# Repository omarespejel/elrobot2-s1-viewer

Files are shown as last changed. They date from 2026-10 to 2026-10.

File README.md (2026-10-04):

# ElRobot2: design versions

Open the site from this repository's GitHub Pages link. The landing page shows the versions of a robot-arm
design that restocks cans and PET bottles through the rear of a convenience-store cooler, with the numbers
that separate them.

## Contents

* `index.html`: versions (S1 v1.1, S2-RC2 release candidate), version history, caveats.
* `viewer/index.html`: interactive 3D viewer of S1 v1.1 (a single self-contained page with six simulation replays).
* `viewer-s2/index.html`: interactive 3D viewer of the S2-RC2 neck-grip hand on the S1 arm (a single self-contained page with seven simulation replays).
* `report.html`: the S1 design report (third round, 2 October 2026).
* `report-s2.html`: the S2-RC2 design report (4 October 2026).
* `docs/`: parameters, test plan, risk register, review log, evidence table, measurement sheet, track reports (Hand, Wrist, Simulation), desk-research pack and module notes.
* `img/`: figures used in the reports.

## What this is and is not

* S1 (top-down gripper) and S2-RC2 (collar jaws that hold a bottle by the neck) are drawn in CAD, checked with exact-mesh
  interference tests and finite-element or closed-form strength checks, and simulated in MuJoCo on a stand-in bench.
  The viewers replay those simulations on the CAD.
* The cooler outline in the viewers is illustrative. Rack dimensions in the reports are inferred from public
  catalogues (US manufacturers, Mexican resellers); no real cooler was measured. The S2-RC2 bottle neck is assumed (PCO-1881) until it is measured.
* **Nothing in this design has been printed, built or measured.** Every dimension, mass and margin is CAD,
  hand calculation, simulation or desk research.
* Scope: aluminium cans (S1) and one-way PET bottles (S2-RC2: 500 and 600 mL verified, 1 L conditional). Glass and returnable containers are out of scope.

The pages carry a noindex tag so that search engines are asked to skip them.

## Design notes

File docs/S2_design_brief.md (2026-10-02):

# S2 end-of-arm design brief: offset wrist, neck-jaw (PET) and flat clamp (cans)

Status: concept brief written on 2026-10-02 from the desk research (ElRobot2_desk_research_pack.md). No S2 part exists in CAD, no S2 motion has been simulated, and nothing has been tested. Values marked ASSUMED or VERIFY must be checked on the first bottle or print.

## 1. Problem

The v1 stack (gripper, J3 servo and L2 cover) stands 140 mm above the object top. A standard rack leaves 15-109 mm above a 600 mL bottle (pitch 0.287-0.381 m, structure 30 mm, margin 5 mm). v1 therefore cannot serve a 600 mL or larger PET bottle in any of the five standard configurations (Figure 9); a 500 mL bottle fits only in the sparsest rack and only if the structure is thinner than about 26 mm. Only a part that is thin where it enters the shelf tunnel (y above 245 mm) can.

## 2. Requirements

| ID | Requirement | Value | Basis |
|---|---|---|---|
| R1 | Structure above the cap inside the tunnel (neck-jaw) | at most 15 mm | gap 15 mm at 0.287 m |
| R2 | Structure above the can top inside the tunnel (flat clamp) | at most 50 mm | gap 94 mm for a tall can at 0.287 m; 50 mm leaves margin |
| R3 | J3 servo, end of L2 and every part taller than R1/R2 | stay at y at most 233 mm at the place pose | tunnel mouth at y = 253 mm, 20 mm margin |
| R4 | Tool offset L3 (J3 axis to neck axis) | 100 mm (85-130 mm) | stack front edge 230 mm; J3 radius 205-273 mm inside 170-385 mm |
| R5 | Static moment at J3 | 0.83 N*m (0.65 kg), 1.25 N*m (1.07 kg) | tool 0.20 kg at 100 mm |
| R6 | J3 bearing pair | two 6701-2RS, 30 mm apart: 28-42 N per bearing | 6701 is in the inventory (x20) |
| R7 | L3 bar stiffness | section at least 6000 mm4 in PETG (20 x 16 mm: 0.6 mm droop) or aluminium | 20 x 10 mm droops 2.5 mm |
| R8 | Tool mass | at most 0.25 kg | v1 gripper 0.336 kg |
| R9 | Hold | form closure on the support ring for PET; friction not required | friction is unmeasured (0.2-1.0 in the literature) |
| R10 | Accelerations while a bottle hangs | at most 0.3 g | swing about the neck |
| R11 | Lane | 75 mm (600 mL class), 90 mm (1 L); bottle clearance 3.6-5 mm per side | glide data |
| R12 | Tote | single row, pitch at least 85 mm, open on the arm side, necks reachable horizontally | neck-jaw approach is horizontal |
| R13 | Rack mock-up | pitch adjustable 0.29-0.44 m in 10 mm steps, 75 mm lane inserts, 6-8 deg slope | envelope range |

## 3. Offset wrist

J3 keeps its servo (STS3215 C018) and flange (50 mm, bolts on a 36 mm square). An adapter carries a bearing housing (two 6701-2RS) and the L3 bar, so that the servo transmits torque only and the bearings carry the moment. The tool centre point is the neck axis: J3 = TCP - L3 * u(heading). For lane targets at y = 305 mm the J3 axis sits at y = 205 mm; the stack front edge is then 230 mm. VERIFY: the existing J3 pin and its bearing (14 mm pin, 46 mm flange in the v1 CAD) were designed for a hanging gripper with its centre of mass on the axis; if they cannot take 1.25 N*m, replace the pin by the bearing housing (one small part).

## 4. Neck-jaw (PET)

- Two jaw plates, 3 mm thick, closing along x just below the support ring (ring underside about 18 mm below the cap top, ASSUMED from the 17.0 mm finish height; VERIFY in H1), a fixed back stop behind the neck, a U-notch of about 30 mm (ASSUMED: ring outside diameter 33 mm, so 1.5 mm ledge per side; the neck under the ring is about 25 mm in the standards and 24.5 mm is the smallest under-neck diameter in an air-conveyor catalogue; VERIFY on 5-10 bottles). Air conveyors use the same principle for empty bottles. Jaw stroke about 6 mm per side (open 40 mm, closed 28 mm), so a small-stroke linkage on one STS3215 is enough.
- The weight rests on the ring ledges (about 30 mm2 of contact: 0.2 MPa for 0.65 kg, 0.35 MPa for 1.07 kg); the closing force (at least 10 N on the neck) only prevents swing.
- Jaw mechanism block (servo and linkage) behind the neck, top at most 8 mm above the cap, partly inside the tunnel mouth (front at y = 275 mm).
- Acquire: approach horizontally at ring height minus 3 mm until the neck touches the back stop, close, lift 5 mm so the ring seats, then carry. Release: lower to the glide, open, retreat along -y.
- Open questions: free neck below the ring (3 mm jaw needs at least 4 mm), tamper bands and sports caps, sleeve labels, swing damping.

## 5. Flat clamp (cans)

Rack-and-pinion clamp with the pinion axis along x and one rack above and one below it (stack: pinion 24 mm + two racks 6 mm + clearances, about 48 mm), servo lying behind the clamp in the corridor, fingers closing along the lane axis as in v1. Clamp force and pad parameters as v1 (34.7 N per finger rated, 41.7 N cap); cans need 14 N at friction 0.4 and 19 N at 0.3. Printed TPU 95A pads are acceptable for cans; use cast polyurethane or silicone pads for a 1 L.

## 6. What S2 reuses

Z module, base, J1/J2 turret, L1, L2, electronics, camera and the calibration scripts. New parts: adapter and bearing housing, L3 bar, neck-jaw, flat clamp, tote tray (single row), rack mock-up with adjustable pitch and 75 mm lane inserts. The v1 gripper stays as a development tool for level-1 (open-top) tests.

## 7. Validation sequence

1. CAD of the new parts with fit checks against the STS3215, a PCO-1881 neck model (ring 33 mm ASSUMED) and a rack model at pitches 0.287, 0.318 and 0.381 m; reach study over five lanes (75 and 90 mm) and the tote.
2. MuJoCo: a bottle hanging from the jaws (ring contact), swing under planned accelerations, release into a 75 mm lane, placement error budget (clearance 3.6-5 mm against servo backlash of 3.4 mm at full reach).
3. Bench (Phase H1-H6 of the test plan): printed neck stub, then real bottles, then rack mock-up.
4. Gate: if H3 (placement into a 75 mm lane at 0.318 m) is below 9 of 10 after two design iterations, build the push-in plate.

## 8. Risks (also in the risk register)

Neck geometry variability; swing; placement tolerance in 75 mm lanes; J3 moment; the 5 mm margin and 30 mm structure thickness are assumptions; a Z range of 0.37-1.06 m reaches only 2-3 shelves of a 1.9-2.2 m rack.

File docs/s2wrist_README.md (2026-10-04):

# S2-RC2 WRIST track - J3 verification, CAN-mode bar, J3 kits, mode switch, reach (file prefix s2wrist_)

Generated by `s2wrist_make_readme.py` from the CSV/JSON files named in brackets, 2026-10-03.  Environment `robodesign` (cadquery 2.8.0, trimesh 5.1.0, manifold3d, numpy/pandas).  Frames: arm zeta frame, J3 interface plane z = 62.5 (flange bottom), heading +x in the J3 frame.  All lengths mm, forces N, moments N*m unless a unit is given.  ASSUMED = a value I chose, not measured or published.

## 0. Deviations and open items (read first)

1. **CAN-mode lane placement is NOT validated with this hand: the retreat after release collides (gate G1 not met for CAN lane placement).** Source: the lead's exact-mesh audit of the `s2wrist_can_mode_*_j3frame.stl` meshes (script `s2chk_can.py`, results `s2chk_can_C_v2.csv`, saved by the lead; this track did not run or reproduce it): 36 configurations (lanes 1 / 3 / 5 x levels 0 / 1 x pitch 0.287 / 0.318 m x 3 cans), 16 poses each, neighbouring cans in the other lanes, positive controls pass. Insert 252 / 252, lower 36 / 36 and release 36 / 36 are clean (the 355 mL can can only be lowered to 0.5 mm above the floor margin because the finger tips end 2.0 mm below its bottom). On the straight retreat the first step (the release pose) is clean, but all 216 / 216 later poses collide: `hand_slider_plus` (the front finger, closing axis = heading) against the released can (1.8-48.3 cm3 per pose, median 42.2 cm3). A lift-over needs >= 130 mm of lift to clear the can top, but the hand reaches the tunnel ceiling after 20 mm (p = 0.287 m) / 50 mm (p = 0.318 m) of lift with the 473 mL can and after 50 mm / 80 mm with the 355 mL can, so no lift-over exists; only p = 0.381 m with the 355 mL can has a window (130-140 mm). Consequence: this track's R_can / p_min / arm-clearance results (sections 6.2 and 9) stay valid but cover only insertion, lowering and release; the bar and the mode-switch guide (sections 6 and 7) are valid for **tote picks and geometry only**. What would remove it: section 11, item 12.

2. **Bar pad changed 3.0 -> 5.0 mm** (my earlier note to the lead said 3.0): the 3 mm far-end pad failed my own bar bending check B1 (SF 1.39 for the 473 mL can, with or without the rib) because the cable slot sits at the web/pad step where the moment peaks [s2wrist_bar_variants.csv]. With the 5 mm pad B1 = 3.52 (473 mL), 4.22 (355 mL), 4.13 (slim) [s2wrist_bar_checks.csv: B1]. Consequences: the hand drops 5.0 mm below the J3 plane (was 3.0); R_can 78.0 mm (was 76.0) and p_min(473 mL) 275.2 mm (was 273.2) [s2wrist_cad_rcan.csv]; bar screws M3 x 14 (was x 12); CAN-mode `z_c = z_g + 155 mm` (was 153). A 4 mm-thick, 28 -> 16 mm deep stiffening rib under the web cuts the static droop at the pad to 0.12 mm at 1 g [s2wrist_bar_checks.csv: B6].

3. **The S1 printed J3 chain fails SF >= 2 at every S2 payload** (tie thread SF 0.28, pin key pockets 0.45, horn plate 1.09 at 500 mL; key tabs 0.96 at the 1.0 N*m servo limit) [s2wrist_j3_summary.csv]. The minimal fix is a metal kit (section 5); no printed-only change reaches SF 2.

4. **UNASSESSED: horn-plate screws in the STS3215 POM horn** (checks A7 / K8 / N8): no published thread rating exists. Section 4.6 gives an INDICATIVE number from handbook POM values (ASSUMED). **No STS3215 output-shaft load rating was found** (searched); the kits remove the moment from the servo shaft by design (moment: pin -> two 6701 -> housing), the shaft still carries torque (<= 1.0 N*m) and, in the CNC kit, the weight through the tie.

5. **6701-2RS bearing material is unknown.** Chrome steel (C0r 530 N, AST Bearings) is the primary basis; stainless (W 61701-2RS1, C0r 260 N) is tabulated as a sensitivity. Payload at SF 2: chrome <= 1.46 kg, stainless <= 0.72 kg [s2wrist_j3_limits.json]. The 1.5 L / 2 L stretch payloads cannot be certified at J3 with these bearings.

6. **G1 is only partly assessed by this track**: done = hand + bar + can + J3 kit vs the arm / J3 stack / L2 (all q3), vs the J1 pedestal, clamp, J1 servo, Z carriage plate, column and rail at the used lane and tote poses and all headings, tunnel-ceiling boolean for R_can, all with positive controls [s2wrist_cad_interference.csv, s2wrist_cad_world_*.csv, s2wrist_cad_rcan.csv]. NOT done: the full rack mock-up (neighbouring lanes, dividers, shelf plate, tote) because no s2rack_ geometry exists yet; hand extents are in section 9 for that check.

7. Models are beam / closed-form (no FEA). ASSUMED values: stress concentration factors, insert knock-down 0.25, E(PETG) 1800 MPa, Al / steel repeated allowables (6061 60, 7075 100, steel 100 MPa), bond strength 2 MPa, thread factors 0.6, servo-register scaling, mode-switch bench times, all prices.

8. Hand data are the lead's first CAD numbers (0.399 kg + 11.7 g camera plate, COM 2.7 / 11.1 / 12.8): re-run `s2wrist_run_all.sh` when the Hand track publishes the final hand. The Sim track's logged J3 peaks (type C: Mh 3.16 / 3.89 N*m, Fz 29.7 / 35.2 N) are evaluated in 4.5 as given; I did not verify them.

9. Tote: a straight -x approach is limited to 26.0 mm at pocket y = 0 and 58.5 mm at y = 100 (>= 120 mm at y = 200 / 300); the lead accepted a vertical drop-over for tote picks [s2wrist_reach_tote_approach.csv].

10. P2 (stiffer servo retention) is an assessment only, no CAD (section 10).

## 1. Files

| file | content |
|---|---|
| s2wrist_common.py | parameters + load model (single source for every script) |
| s2wrist_j3_verify.py | J3 chain checks, 4 configurations -> s2wrist_j3_{loads,checks,summary,governing,bearing_table,torque_register}.csv, s2wrist_j3_limits.json |
| s2wrist_j3_sfcalc.py | SF of every check for ANY (M, Fz): `sf_at(M_Nm, Fz_N)`; -> s2wrist_j3_moment_at_SF2.csv, s2wrist_j3_sim_peak_check.csv |
| s2wrist_build.py | CadQuery: can bar, CNC shaft-flange, Al horn plate -> .step/.stl, s2wrist_bar_params.json, s2wrist_parts_table.csv |
| s2wrist_nckit.py / s2wrist_nc_dxf.py | NO-CNC kit parts (.step/.stl) and the two cutting profiles (.dxf) |
| s2wrist_cadlib.py / s2wrist_cadcheck.py / s2wrist_worldcheck.py / s2wrist_rcan.py | manifold3d interference battery with positive controls, world sweeps, R_can |
| s2wrist_barlib.py / s2wrist_bar_checks.py | bar section properties (CAD slices), strength, droop -> s2wrist_bar_checks.csv, s2wrist_bar_sections.csv |
| s2wrist_modeswitch.py | mode-switch step list and time budget -> s2wrist_modeswitch_steps.csv, s2wrist_modeswitch_parts.csv |
| s2wrist_order_list.py | paste-ready purchase / RFQ text -> s2wrist_j3_order_list.csv / .md |
| s2wrist_bar_variants.py | bar design history (3 mm pad / rib / 5 mm pad) -> s2wrist_bar_variants.csv |
| s2wrist_can_mode_export.py | CAN-mode hand (static + 2 finger sliders) and bar meshes in the J3 frame + placement / mass JSON -> s2wrist_can_mode_{hand_static,hand_slider_plus,hand_slider_minus,bar}_j3frame.stl, s2wrist_can_mode_interface.json (section 14) |
| s2wrist_make_readme.py | this README, generated from the CSV / JSON files |
| s2wrist_reach.py | analytic IK, lanes and tote -> s2wrist_reach_{path,summary,outside_limits,tote_approach}.csv |
| s2wrist_com.py | v1 hand COM from the 13-solid gripper STEP -> s2wrist_v1_hand_com.json |
| s2wrist_run_all.sh | regenerates everything in dependency order (~8 min) |

## 2. Load model (P1.1 input) [s2wrist_common.py, s2wrist_j3_loads.csv]

Design combination at the J3 interface plane: vertical force W = 1.5 g (m_hand + m_payload) (0.5 g carry factor of the task), horizontal V = 0.3 g m along the heading together with it, plus a lateral 0.3 g and the lateral COM offset; M_res = sqrt(M^2 + M_lat^2) with M = sum m g (1.5 x + 0.3 z_below).  PET hand 0.4107 kg (0.399 base + 0.0117 camera plate; COM 10.78 mm ahead, 4.07 mm lateral, 49.41 mm below the J3 plane); CAN hand 0.44 kg as designed (printed 0.3355 kg), COM 6.79 mm ahead of the pad datum; bar 0.0696 kg.

| mode | case | payload kg | total kg | M_res N*m | W N | lower 6701 radial N |
|---|---|---|---|---|---|---|
| PET | 500 mL | 0.519 | 0.930 | 1.245 | 13.7 | 94.6 |
| PET | 600 mL | 0.650 | 1.061 | 1.561 | 15.6 | 118.0 |
| PET | 1 L | 1.072 | 1.483 | 2.602 | 21.8 | 194.9 |
| PET | 1.5 L | 1.605 | 2.016 | 3.896 | 29.7 | 290.6 |
| PET | 2 L (stretch) | 2.130 | 2.541 | 5.164 | 37.4 | 384.4 |
| CAN | 355 mL can | 0.382 | 0.892 | 1.610 | 13.1 | 120.5 |
| CAN | 355 slim can | 0.382 | 0.892 | 1.625 | 13.1 | 121.5 |
| CAN | 473 mL can | 0.507 | 1.017 | 1.880 | 15.0 | 140.5 |
| CAN | 473 mL can (hand 0.336 kg task value) | 0.507 | 0.913 | 1.690 | 13.4 | 126.3 |

Governing case: the heaviest bottle. For the product scope (<= 1 L) it is the 1 L bottle (M_res 2.602 N*m); the CAN 473 mL can (1.880 N*m) lies between the 600 mL and 1 L bottle cases. Governing check up to 1 L, by kit: the 6701 bearings (C8) for KIT_CNC_7075, the Al flange plate N2 / the dowels N6a for KIT_NC, the pin K3 / the tie thread K6 for KIT_CNC_6061 [s2wrist_j3_governing.csv: governing_check].

## 3. Frames and inputs

- **J3 frame** (all CAD checks): origin on the J3 axis, z = arm zeta (J3 interface plane = flange bottom = 62.5), +x = heading (toward the bore / pad datum), y lateral. Arm assembly STEP -> J3 frame: (x, y, z) -> (y - 400, -x, z) (J1 at the origin, J2 at (0, 200), J3 at (0, 400)).
- **Hand (S1 gripper STEP, body frame) -> J3 frame in CAN mode**: x + 104, y, z - 5.5 (the pad drops the body 5.0 mm below the J3 plane; the hand is mounted 0.5 mm lower than the arm frame). The CAN hand's closing axis is along the heading; the PET hand is rotated 90 deg (Hand track).  Interface note for Sim: in CAN mode `z_c = z_g + 155 mm`.
- **Z module -> arm frame**: z - 550 (the carriage-plate holes at z = 610 / 645 / 680 coincide with the pedestal holes at zeta 60 / 95 / 130; x, y identical).
- Inputs: master spec v4 (S2_RC2_master_spec.md), arm_assembly.step, zmod_assembly.step, gripper_assembly_gap70.step, s2hand_* (Hand track), S1 BOM, lead messages of 2026-10-03 (hand 0.399 kg + 11.7 g camera plate, COM 2.7 / 11.1 / 12.8, bore at 104 mm, seat plane zeta -12.3).

## 4. J3 chain verification (P1.1, gate G3)

### 4.1 Result

The S1 printed chain fails SF >= 2 at every S2 payload, starting with the central M3 tie in its printed pilot (SF 0.28 at 500 mL, 0.13 at 1 L), the pin key pockets (0.45 / 0.22) and the printed horn plate (1.09 / 0.53); the cruciform key tabs are over-stressed at the 1.0 N*m servo limit even with no payload (SF 0.96). Minimal fix = move the moment path into metal: a one-piece shaft-flange (pin + flange) running in the two 6701 bearings, so the moment goes pin -> bearings -> housing and the tie and horn plate carry only the weight and the servo torque. With that fix the 6701 bearings (chrome) govern up to 1.46 kg per bottle; the CNC 7075 kit itself is good to 1.7 kg (pin at the hub fillet, K3), the CNC 6061 kit to 1.02 kg (K3), and the NO-CNC kit to 1.38 kg (3 mm Al flange plate, N2) [s2wrist_j3_summary.csv: max_bottle_kg_at_SF2]. The 1 L bottle (1.07 kg) is therefore the largest S2 payload that passes SF 2 on the 7075 and NC kits with chrome 6701 bearings; with stainless 6701 the bearings reach only SF 1.33 at 1 L, and the 6061 kit SF 1.90 (K3).

### 4.2 Safety factors by option and payload [s2wrist_j3_summary.csv; per-case detail with demand / capacity / basis in s2wrist_j3_checks.csv]

| option | check | element | SF 500 mL | 600 mL | 1 L | 1.5 L | 2 L | max bottle kg at SF 2 |
|---|---|---|---|---|---|---|---|---|
| AS_BUILT | A2 | flange 46x46x3 PETG plate between the 36x36 screws and the D14 collar | 1.89 | 1.53 | 0.93 | 0.63 | 0.48 | < 0.52 |
| AS_BUILT | A3 | flange cruciform key tabs 3x10x2.5 (torque 1.0 N*m servo limit) | 0.96 | 0.96 | 0.96 | 0.96 | 0.96 | < 0.52 |
| AS_BUILT | A4a | printed pin D11.95/bore 3.4, ring section | 1.31 | 1.05 | 0.63 | 0.42 | 0.32 | < 0.52 |
| AS_BUILT | A4b | printed pin, key-pocket zone (cruciform 3.3x10.3x2.6): lobed net section | 0.45 | 0.36 | 0.22 | 0.14 | 0.11 | < 0.52 |
| AS_BUILT | A5 | central tie M3x20 (as built, 2.0 mm engaged) in the printed plate post pilot D | 0.28 | 0.22 | 0.13 | 0.09 | 0.07 | < 0.52 |
| AS_BUILT | A5b | central tie M3x25 (7.0 mm engaged) in the printed plate post pilot D2.6 | 0.96 | 0.77 | 0.47 | 0.31 | 0.24 | < 0.52 |
| AS_BUILT | A6 | horn plate D24x3.5 PETG under the tie force | 1.09 | 0.87 | 0.53 | 0.35 | 0.27 | < 0.52 |
| KIT_CNC_7075 | K2 | 7075-T6 shaft-flange 46x46x3 plate between the 36x36 screws and the D14 hub | 9.46 | 7.63 | 4.66 | 3.14 | 2.38 | >= 2.13 |
| KIT_CNC_7075 | K3 | 7075-T6 pin D11.95/bore 3.4 above the hub shoulder (z 67.1) | 6.59 | 5.26 | 3.16 | 2.11 | 1.6 | 1.7 |
| KIT_CNC_7075 | K4 | 2 integral pegs D3x2 (r 4 mm) on the pin top: torque 1.0 N*m | 8.16 | 8.16 | 8.16 | 8.16 | 8.16 | >= 2.13 |
| KIT_CNC_7075 | K6 | M3x25 tie into the M3 thread of the Al horn plate (2.0 mm engaged) | 6.22 | 6.15 | 5.92 | 5.67 | 5.43 | >= 2.13 |
| KIT_CNC_7075 | K7 | Al horn plate 3.5 mm under the tie (supported on the pin-top annulus) | 6.55 | 6.47 | 6.24 | 5.97 | 5.72 | >= 2.13 |
| KIT_CNC_6061 | K2 | 6061-T6 shaft-flange 46x46x3 plate between the 36x36 screws and the D14 hub | 5.68 | 4.58 | 2.8 | 1.89 | 1.43 | 1.51 |
| KIT_CNC_6061 | K3 | 6061-T6 pin D11.95/bore 3.4 above the hub shoulder (z 67.1) | 3.95 | 3.16 | 1.9 | 1.27 | 0.96 | 1.02 |
| KIT_CNC_6061 | K4 | 2 integral pegs D3x2 (r 4 mm) on the pin top: torque 1.0 N*m | 4.9 | 4.9 | 4.9 | 4.9 | 4.9 | >= 2.13 |
| KIT_CNC_6061 | K6 | M3x25 tie into the M3 thread of the Al horn plate (2.0 mm engaged) | 3.73 | 3.69 | 3.55 | 3.4 | 3.26 | >= 2.13 |
| KIT_CNC_6061 | K7 | Al horn plate 3.5 mm under the tie (supported on the pin-top annulus) | 3.93 | 3.88 | 3.74 | 3.58 | 3.43 | >= 2.13 |
| KIT_NC | N2 | Al 3 mm flange plate (6061-T6 / 5052-H32 or better) between the 36x36 screws a | 5.22 | 4.21 | 2.57 | 1.73 | 1.31 | 1.38 |
| KIT_NC | N3 | D12 steel rod with 3 tapped M2.5 holes on r 3.5 (net section) at the lower bea | 8.2 | 6.55 | 3.94 | 2.64 | 1.99 | 2.12 |
| KIT_NC | N4a | flange-rod screw M2.5 8.8 (worst of 3): tension M/9.5 mm + W/3 | 8.7 | 6.96 | 4.2 | 2.81 | 2.12 | >= 2.13 |
| KIT_NC | N4b | thread strip of M2.5 in the mild-steel rod (4 mm engaged) | 7.09 | 5.68 | 3.42 | 2.29 | 1.73 | 1.84 |
| KIT_NC | N4c | csk head pull-through in the 3 mm Al plate (D5.0 cone, 1.5 mm rim) | 6.05 | 4.84 | 2.92 | 1.95 | 1.47 | 1.56 |
| KIT_NC | N4d | rod end face toe contact on the Al plate | 5.45 | 4.35 | 2.61 | 1.74 | 1.31 | 1.4 |
| KIT_NC | N6a | 2 x D3 steel dowels (ISO 2338 3x6) pressed in the rod top: torque 1.0 N*m | 4.92 | 4.92 | 4.92 | 4.92 | 4.92 | >= 2.13 |
| KIT_NC | N7 | top face bond rod / Al plate (retaining compound or epoxy): holds the weight | 16.53 | 14.49 | 10.37 | 7.63 | 6.05 | >= 2.13 |
| all options | C8 | 2 x 6701-2RS (lower bearing, centre spacing 14 mm), C0r 530 N | 5.6 | 4.49 | 2.72 | 1.82 | 1.38 | 1.46 |
| all options | C8s | 2 x 6701-2RS STAINLESS (W 61701-2RS1), C0r 260 N | 2.75 | 2.2 | 1.33 | 0.89 | 0.68 | 0.71 |
| all options | C1 | hand screws 4xM3x12 on 36x36 -> carrier / bar heat-set inserts | 9.18 | 7.41 | 4.53 | 3.05 | 2.31 | >= 2.13 |
| all options | C9a | housing 48x48 flange: 4 x M3 into heat-set inserts (38x38) | 9.63 | 7.77 | 4.75 | 3.2 | 2.43 | >= 2.13 |
| all options | C9b | housing D26 cylinder wall (OD26/ID18.1) between lower bearing and the 48x48 fl | 17.22 | 13.82 | 8.36 | 5.61 | 4.24 | >= 2.13 |
| all options | C9c | housing seat for the lower 6701 (D18.1 x 4 mm) | 11.95 | 9.59 | 5.8 | 3.89 | 2.94 | >= 2.13 |
| all options | C10a | L2 floor at J3 (7 mm, 3.8 mm under the D6 counterbore): housing-screw head pul | 15.55 | 12.55 | 7.68 | 5.18 | 3.92 | >= 2.13 |
| all options | C10b | L2 floor strip between servo-pocket wall and side wall (8.35 mm span, 3.8 mm u | 34.68 | 28.0 | 17.12 | 11.54 | 8.75 | >= 2.13 |

A7 / K8 / N8 (horn-plate screws in the POM horn) are UNASSESSED (no published thread rating). Torque-driven rows (A3, K4, N6a) do not depend on the payload: they use the 1.0 N*m servo limit.

### 4.3 Moment at SF = 2 per element and option (for comparison with a measured or simulated peak) [s2wrist_j3_moment_at_SF2.csv]

Values are the resultant interface moment M_res (N*m) at which SF = 2, as `design-coupled (pure)`: design-coupled keeps W = 8.39 N per N*m of moment (the 1 L bottle ratio) and V = 0.2 W, i.e. the vertical and horizontal forces that accompany the moment in the design combination; pure = W = V = 0. `s2wrist_j3_sfcalc.sf_at(M_Nm, Fz_N)` returns the SF of every check for any measured (M, Fz). Repeated-load allowables; for a one-off peak the single-event capacity is higher (PETG x1.75, Al x2.5, steel x1.5; bearings are already static).

| element (check) | AS_BUILT | KIT_CNC_7075 | KIT_CNC_6061 | KIT_NC |
|---|---|---|---|---|
| 6701-2RS chrome steel, C0r 530 N (C8) | 3.54 (3.71) | 3.54 (3.71) | 3.54 (3.71) | 3.54 (3.71) |
| 6701-2RS stainless, C0r 260 N (C8s) | 1.74 (1.82) | 1.74 (1.82) | 1.74 (1.82) | 1.74 (1.82) |
| flange plate (A2 / K2 / K2 / N2) | 1.21 (1.34) | 6.07 (6.71) | 3.64 (4.03) | 3.35 (3.7) |
| pin, nominal section (A4a); pin / rod with fillet or tapped holes (K3 / K3 / N3) | 0.82 (0.83) | 4.12 (4.16) | 2.47 (2.5) | 5.13 (5.21) |
| printed pin key-pocket zone (A4b) | 0.28 (0.28) | - | - | - |
| tie screw thread: M3x20 as built (A5), M3x25 (A5b / K6) | 0.17 (0.18) | 42.8 (> 60) | 18.53 (> 60) | - |
| M3x25 tie in the printed post (A5b) | 0.61 (0.64) | - | - | - |
| horn plate bending (A6 / K7 / K7) | 0.69 (0.72) | 46.01 (> 60) | 20.45 (> 60) | - |
| rod-plate screws: M2.5 bolt tension (N4a) | - | - | - | 5.46 (5.6) |
| rod-plate screws: thread strip in the rod (N4b) | - | - | - | 4.45 (4.57) |
| rod-plate screws: csk pull-through in the Al plate (N4c) | - | - | - | 3.79 (3.89) |
| rod end face toe contact on the Al plate (N4d) | - | - | - | 3.39 (3.39) |
| top bond rod / horn plate (N7) | - | - | - | 13.49 (> 60) |
| hand / bar screws -> inserts (C1) | 5.89 (6.52) | 5.89 (6.52) | 5.89 (6.52) | 5.89 (6.52) |
| housing screws -> inserts (C9a) | 6.18 (6.88) | 6.18 (6.88) | 6.18 (6.88) | 6.18 (6.88) |
| housing wall (C9b), 6701 seat (C9c) | 10.88 (11.41) | 10.88 (11.41) | 10.88 (11.41) | 10.88 (11.41) |
| L2 floor under the housing screw heads (C10a) | 9.99 (11.11) | 9.99 (11.11) | 9.99 (11.11) | 9.99 (11.11) |
| horn-plate screws in the POM horn (A7 / K8 / N8) | UNASSESSED | UNASSESSED | UNASSESSED | UNASSESSED |

Governing element per option (smallest moment at SF 2, stainless bearings excluded): AS_BUILT: 0.17 N*m (A5); KIT_CNC_7075: 3.54 N*m (C8); KIT_CNC_6061: 2.47 N*m (K3); KIT_NC: 3.35 N*m (N2).

Torque-limited elements at the 1.0 N*m servo limit (moment-independent):

| option | check | element | SF at 1.0 N*m | torque (N*m) at SF 2 |
|---|---|---|---|---|
| AS_BUILT | A3 | S1 key tabs, torque | 0.96 | 0.48 |
| KIT_CNC_7075 | K4 | CNC pegs D3, torque | 8.16 | 4.08 |
| KIT_CNC_6061 | K4 | CNC pegs 6061, torque | 4.9 | 2.45 |
| KIT_NC | N6a | NC dowels, torque | 4.92 | 2.46 |
| KIT_NC | N5a | NC flange-rod screws in shear, torque | 7.93 | 3.96 |

### 4.4 Bearings: both C0r values [s2wrist_j3_bearing_table.csv]

| mode | case | payload kg | M_res N*m | P0 lower 6701 N | SF chrome 530 N | SF stainless 260 N |
|---|---|---|---|---|---|---|
| PET | 500 mL | 0.519 | 1.245 | 94.6 | 5.6 | 2.75 |
| PET | 600 mL | 0.650 | 1.561 | 118.0 | 4.49 | 2.2 |
| PET | 1 L | 1.072 | 2.602 | 194.9 | 2.72 | 1.33 |
| PET | 1.5 L | 1.605 | 3.896 | 290.6 | 1.82 | 0.89 |
| PET | 2 L (stretch) | 2.130 | 5.164 | 384.4 | 1.38 | 0.68 |
| CAN | 355 mL can | 0.382 | 1.610 | 120.5 | 4.4 | 2.16 |
| CAN | 355 slim can | 0.382 | 1.625 | 121.5 | 4.36 | 2.14 |
| CAN | 473 mL can | 0.507 | 1.880 | 140.5 | 3.77 | 1.85 |
| CAN | 473 mL can (hand 0.336 kg task value) | 0.507 | 1.690 | 126.3 | 4.2 | 2.06 |

Payload at SF 2 (PET bottles, interpolated): chrome <= 1.46 kg, stainless <= 0.72 kg [s2wrist_j3_limits.json]. With stainless 6701 only the 500 mL and 600 mL bottles reach SF 2; the 473 mL can reaches 1.85 with the 0.44 kg hand and 2.06 with the task's 0.336 kg hand. Ask the bearing seller for the material (chrome steel, 'GCr15 / 52100') before relying on 1 L.

### 4.5 Cross-check against the Sim track's logged J3 peaks [s2wrist_j3_sim_peak_check.csv]

Lead message: type C Mh 3.16 / 3.89 N*m with Fz peaks 29.7 / 35.2 N (500 / 600 mL), type F Mh 0.67 / 0.82 N*m, versus my design M_res 1.25 / 1.56 N*m (static weight x 1.5 only 0.57 N*m at 500 mL). Treated here as (M_res = Mh, W = Fz, V = 0.2 Fz ASSUMED); type F uses Fz = design W. SF on the repeated-load basis:

| element | option | check | Sim C 500 mL | Sim C 600 mL | design 500 mL | design 600 mL |
|---|---|---|---|---|---|---|
| 6701 chrome (all kits) | KIT_CNC_7075 | C8 | 2.23 | 1.81 | 5.6 | 4.49 |
| 6701 stainless | KIT_CNC_7075 | C8s | 1.09 | 0.89 | 2.75 | 2.2 |
| 7075 flange plate | KIT_CNC_7075 | K2 | 3.8 | 3.1 | 9.46 | 7.63 |
| 7075 pin | KIT_CNC_7075 | K3 | 2.6 | 2.11 | 6.59 | 5.26 |
| 6061 pin | KIT_CNC_6061 | K3 | 1.56 | 1.27 | 3.95 | 3.16 |
| 6061 flange plate | KIT_CNC_6061 | K2 | 2.28 | 1.86 | 5.68 | 4.58 |
| NC flange plate | KIT_NC | N2 | 2.09 | 1.71 | 5.22 | 4.21 |
| NC rod toe contact | KIT_NC | N4d | 2.15 | 1.74 | 5.45 | 4.35 |
| NC rod | KIT_NC | N3 | 3.24 | 2.63 | 8.2 | 6.55 |
| S1 printed pin pockets | AS_BUILT | A4b | 0.18 | 0.14 | 0.45 | 0.36 |
| S1 tie thread | AS_BUILT | A5 | 0.11 | 0.09 | 0.28 | 0.22 |

Reading: if the type-C peaks are real and repeated, the 7075 kit stays at SF >= 2.11 and the chrome 6701 at 2.23 / 1.81; the 6061 pin (1.56 / 1.27) is below 2 at both peaks and the NC plate (2.09 / 1.71) at the 600 mL peak on the repeated basis, but both are above 2 on the single-event basis (x2.5 Al); stainless 6701 (1.09 / 0.89) and the printed chain (all < 1) do not survive. If the peaks are a sub-10 ms grasp / lift impulse, the static C0r rating of the bearings and the single-event allowables are the relevant ones.

### 4.6 J3 servo torque-limit register [s2wrist_j3_torque_register.csv; scaling ASSUMED linear: register = N*mm / 2943 x 1000, 2.94 N*m = 30 kg*cm stall at 12 V]

| mode | case | I_J3 kg m2 | T peak alpha 2 rad/s2 | alpha 5 | alpha 10 | hold vs lateral 0.3 g |
|---|---|---|---|---|---|---|
| PET | 500 mL | 0.00684 | 0.034 | 0.054 | 0.088 | 0.172 |
| PET | 600 mL | 0.00835 | 0.037 | 0.062 | 0.103 | 0.212 |
| PET | 1 L | 0.01338 | 0.047 | 0.087 | 0.154 | 0.341 |
| PET | 1.5 L | 0.0199 | 0.06 | 0.119 | 0.219 | 0.504 |
| PET | 2 L (stretch) | 0.02692 | 0.074 | 0.155 | 0.289 | 0.665 |
| CAN | 355 mL can | 0.01095 | 0.042 | 0.075 | 0.129 | 0.268 |
| CAN | 473 mL can | 0.01237 | 0.045 | 0.082 | 0.144 | 0.307 |

T = I_J3 x alpha + 20 N*mm bearing friction (ASSUMED) at alpha = 2 / 5 / 10 rad/s2; holding torque = torque about J3 needed to keep the hand orientation against a lateral 0.3 g acceleration of the offset COM.  **Recommended register, PET mode: 200 (about 0.59 N*m) with either metal kit** - 3.8x the 10 rad/s2 peak and 1.7x the hold torque of the 1 L bottle, and the pegs / dowels still see SF >= 8.2 / 4.9 at the 1.0 N*m spec limit (register 340 is acceptable but gives no benefit). **With the S1 printed key tabs still installed (interim): 130 (0.38 N*m)** - tab SF 2.5 on the single-event basis; the tabs need <= 0.48 N*m for SF 2 and the printed chain must not carry any bottle (section 5.3).  CAN mode: 200 (hold 0.31 N*m for the 473 mL can).  Calibrate the register with a spring-scale test before trusting the scaling.

INDICATIVE only (not a rating): handbook acetal shear 50 MPa (ASSUMED), thread factor 0.6, M3 with 2.2 mm engaged (M3 x 6 in the 3 mm POM horn) gives about 560 N per screw. Demand per screw: 43.0 N for the weight + tie preload path (K8, 1 L, CNC kit), 20.9 N at the 200 register and 35.4 N at the 1.0 N*m limit for the torque path (T / (4 x 7.07 mm)). The measure that removes the weight from the POM threads is process, not CAD: bond the two bearing inner races to the pin / rod with retaining compound (section 5.2) so the weight goes through the bearings.

### 4.7 Models, limits

Beam / closed-form checks only (cantilever analogy for the flange plates, numerical net sections for the pin and rod, bolt-group worst-bolt formula M / 50.9 mm on the 36 x 36 pattern, Roark plates for the horn plates). ASSUMED: Kt 2 (printed pin pockets and hub fillet), Kt 1.5 (rod holes), insert capacity = CNC Kitchen PETG M3 Ruthex pull-out 119 kg x 5/5.7 x 0.25 = 256 N, PETG 20 / 35 MPa in-plane repeated / single x 0.5 across layers (S1 rule), Al repeated 60 (6061-T6) / 100 (7075-T6) MPa, steel 100 MPa, bond 2 MPa, thread factor 0.6. No FEA, no fatigue test; a static proof hang-test at 104 mm is part of the build (section 5.2).

## 5. The fix: J3 kits, recommendation, order list

Both kits keep the S1 interface unchanged (46 x 46 x 3 flange, 4 x M3 on 36 x 36, J3 plane 62.5, pin through the two 6701, horn plate D24 at z 85.5, servo, housing, spacer, L2 untouched). **Do not print arm_j3_pin, arm_j3_flange, arm_j3_horn_plate (3 parts, 12 g).** Interference of every kit part with the housing, bearings, spacer, L2, servo, horn and shims is zero (1 mm3 criterion, positive control detected) [s2wrist_cad_interference.csv: F3].

### 5.1 Option A - CNC kit (7075-T6, recommended for the permanent build)

- `s2wrist_j3_shaft_flange` (23.2 g; 46.0 x 46.0 x 25.0): 46 x 46 x 3 flange + D14 x 1.6 hub + D11.95 pin to z 85.5 + 2 integral pegs D3 x 2 at r 4 + tie bore D3.4 with a bottom countersink, one piece (moment goes pin -> bearings). `s2wrist_j3_horn_plate_al` (3.8 g; D24 x 3.5, 4 csk on 10 x 10, 2 peg holes, M3 tapped centre). Tie **M3 x 25** (was x 20), horn screws **M3 x 6** (was x 5; 2.2 mm instead of 1.2 mm engaged in the POM horn).
- 7075-T6 limits (K3 pin at the hub fillet) 1.7 kg per bottle; 6061-T6 allowed as a fallback but then the 1 L bottle is at SF 1.90 (pin) - limit 1.02 kg. Moment at SF 2: 7075 4.12, 6061 2.47 N*m (pin, section 4.3).  Pegs SF 8.2 (7075) at the 1.0 N*m servo limit.

### 5.2 Option B - NO-CNC kit from commodity stock

| part | kind | mass g | bbox mm |
|---|---|---|---|
| nc_rod | purchased 12 mm drillable rod, cut 20.0 + tapped/reamed | 17.45 | 12.0 x 12.0 x 22.0 |
| nc_flange_plate | purchased 3 mm Al plate (6061-T6 / 5052-H32), drilled | 16.37 | 46.0 x 46.0 x 3.0 |
| nc_horn_plate | purchased 3 mm Al plate, drilled | 3.1 | 24.0 x 24.0 x 3.0 |
| nc_collar | printed PETG | 0.1 | 14.6 x 14.6 x 1.6 |
| nc_jig | printed PETG (socket opening down: print with the guide plate on the bed) | 8.68 | 22.0 x 22.0 x 18.0 |

**What each element is and how it is fixed**

1. **Rod**: D12 mm, unhardened steel (AISI 1018 / 1045, 12L14 or annealed silver steel; h9 or better, 11.957-12.000 mm; NOT a hardened chrome linear shaft - cannot be tapped - and not A2 stainless), length **23.0 - t_plate** (20.00 mm for a 3.00 mm plate, 19.83 mm for a 1/8 in plate), both ends faced square (<= 0.05 mm over D12): the end-face squareness sets the hand tilt (0.05 mm / 12 mm = 4 mrad = 0.6 mm at the finger tips).
2. **Rod in the bearings**: both 6701 inner races are bonded to the rod with Loctite 638 (slip-fit retaining compound; datasheet gap fill 0.15-0.25 mm, fixture 5 min, full cure 24 h). The weight then goes rod -> inner races -> balls -> housing lip, not through the POM horn. Keep compound off the seals.
3. **Rod to the horn plate**: 2 steel dowels ISO 2338 D3 x 6 pressed 4 mm into reamed D3.0 holes at (+-4, 0) in the rod top, 2 mm into D3.2 holes of the plate (0.2 mm diametral clearance, inside the 0.25 mm diameter clearance quoted for 638; the compound is not asked to fill more), plus the top face bonded with 638. Torque path at the 1.0 N*m servo limit: dowel shear SF 4.9 [N6a], hole bearing SF >= 10.8 [N6b, N6c]; the bond (N7, 2 MPa ASSUMED) holds the weight with SF >= 6.0.

4. **Rod to the flange plate**: 3 x M2.5 x 8 DIN 7991 flat head (steel 8.8, medium threadlocker) through the plate into 3 tapped M2.5 holes (5 mm of thread) in the rod bottom face on r = 3.5; the rod end face seats on the plate top (toe contact, N4d). No tie screw. The D3.0 holes with 90 deg countersinks let the cones self-centre the screws (+-0.25 mm) on the jig-drilled rod holes.
5. **Axial stack**: printed collar (ring ID 12.2 / OD 14.6 x (4.6 - t_plate): 1.60 mm for a 3.00 mm plate) between the plate top and the lower inner race (compression only); 0.4 mm clearance between the horn plate and the upper inner race, so a failed horn-screw thread lets the plate land on the race (benign).

**Making the holes without a mill**

- *36 x 36 pattern, the three M2.5 holes, the horn-plate holes, the outline*: have a laser / waterjet / CNC-router shop cut both plates from `s2wrist_nc_flange_plate.dxf` and `s2wrist_nc_horn_plate.dxf` (1:1 mm, +-0.1; the CUT layer holds the outline and the through holes). Hand route: print the DXF 1:1 on paper, glue it on the plate, centre-punch, drill; +-0.2 mm is enough because the hand screws have D3.4 clearance holes and the cones self-centre the M2.5 screws. **Exception: the two D3.2 dowel holes of the horn plate** must match the 8.0 mm dowel spacing within about +-0.1 mm: drill them last, after pressing the blank plate onto the dowel tips (marker ink or a transfer punch) to mark the centres, or use the laser-cut DXF. Then countersink with a 90 deg bit: D5.0 on the underside of the three r = 3.5 holes of the flange plate, D6.2 on the underside of the four 10 x 10 holes of the horn plate.
- *The 'D12 hole'*: there is none. The rod is solid and slides through the existing 6701 bores; nothing needs boring.
- *Rod*: cut and face on a lathe (a machinist needs minutes; 1 piece = 20.00 mm) or hacksaw + file against a square block. *Three M2.5 holes*: print `s2wrist_nc_jig` (socket D12.2 x 14 for the rod, guide holes D2.2 on r = 3.5 at 90 / 210 / 330 deg), clamp rod + jig in a drill-press vise, drill D2.05 x 6 deep with a stop collar, tap M2.5 x 0.45 (taper then plug tap, 5 mm of full thread). *Two dowel holes*: same jig, guide holes D3.2 at (+-4, 0), drill D2.9 x 4.5 deep, ream D3.0, press the dowels (3 x 6) in.
- *Assembly from below* (servo, horn and horn plate already in L2 as in the S1 order; the plate is fixed to the horn with 4 x M3 x 6): coat the rod OD in the two race zones and its top face with 638, push the rod up through both bearings until the dowels enter the plate and the top face touches, wipe, fit the collar, offer the flange plate and tighten the 3 x M2.5 with threadlocker (0.3-0.4 N*m), wait 24 h before loading.
- *Proof test (build gate)*: hang a dead weight at 104 mm from the J3 axis for 5 min with the J3 servo torque off, paint-mark the plate / rod / horn plate: no creep. With CHROME 6701: 3.3 kg (1.3 x the 1 L design moment, M = 3.4 N*m, below the 3.54 N*m of SF 2 for the chrome pair). With STAINLESS 6701 (or unknown bearings): 1.7 kg only (M = 1.74 N*m, the moment at SF 2 of the stainless pair; the 3.4 N*m test would load stainless bearings to their static rating). Then a 1.0 N*m torque (10 N at 100 mm) with the servo locked: no slip. Then, with the servo unpowered, twist the hand by hand about J3: free play at the finger tips <= 1 mm (0.007 rad at 143.5 mm); more means oversize dowel holes or an uncured bond. Required for both kits.

Limits: NC kit payload at SF 2 is 1.38 kg (3 mm Al flange plate, N2; 6061-T6 / 5052-H32 assumed - **an unknown 'aluminium sheet' (1100 / 3003) is weaker and invalidates this**), rod bending 2.12 kg (N3), rod-plate screws / toe contact 1.4 kg (N4d); it depends on workmanship (squareness, thread depth, bond), hence the proof test.

### 5.3 Recommendation for the first build

1. **First build (2-3 day print window): option B (NO-CNC)**, if the commodity items (12 mm unhardened rod, 3 mm 6061-T6 / 5052-H32 plate cut from the DXF, M2.5 x 8 + M3 x 6 flat-head screws, D3 x 6 dowels, Loctite 638) are in hand within about two days; every item is a common stock size and a local machinist can face the rod and cut the plates in an hour. It passes SF 2 up to 1.38 kg per bottle (1 L = 1.07 kg: SF 2.57 on the weakest check, N2).

2. **In parallel order 3 sets of option A (7075-T6 CNC)** for the permanent hand: the interfaces are identical, so the swap is the same screws. The CNC kit is not the limiter (pin 1.7 kg, bearings 1.46 kg) and removes the workmanship dependence. CNC lead time 1-2 weeks to Mexico per the lead; the online services list 3-day builds plus 3-7 days express (section 5.4).

3. **Printed S1 chain**: dry fits and no-payload motion only, register 130 (0.38 N*m). It cannot carry a bottle (SF 0.28 at 500 mL, section 4.2). **Do not use 1.5 L or 2 L bottles with either kit** (bearings 1.46 kg chrome / 0.72 kg stainless).

### 5.4 Order list (paste-ready) [s2wrist_j3_order_list.csv, s2wrist_j3_order_list.md; prices are ESTIMATE or WEB, not quotes]

Lot totals (computed): option A parts + screws USD 103-250 (+ express shipping USD 35-70 ESTIMATE), option B consumables + cutting + tools USD 85-266 (the high end includes a 50 mL bottle of Loctite 638 and tools you may already own), common hardware USD 12-30. Price anchors seen on 2026-10-03: Loctite 638 50 mL USD 54.81-92.53 across US industrial retailers (10 mL cheaper, ESTIMATE USD 25-35); 0.125 in 6061-T6 blanks USD 10.84 (3 x 3 in) / 13.38 (4 x 4 in) at tciprecision.com; JLCCNC lists CNC milling and turning 'from USD 5' with a 3 business-day build; a prototype-cost guide (lkprototype.com) lists aluminium CNC prototypes at USD 50-200 and 3qmachining.com 'as low as USD 50'.

| opt | id | item | per arm | order | USD lot | basis |
|---|---|---|---|---|---|---|
| A | A1 | J3 shaft-flange (CNC) | 1 | 3 | 75-180 | ESTIMATE (web anchors) |
| A | A2 | J3 horn plate (CNC) | 1 | 3 | 24-60 | ESTIMATE |
| A | A3 | tie screw M3 x 25 DIN 7991 (flat head, steel 8.8 or A2-70) | 1 | 6 | 2-5 | ESTIMATE |
| A | A4 | horn screws M3 x 6 DIN 7991 (flat head) | 4 | 12 | 2-5 | ESTIMATE |
| B | B1 | steel rod D12 (cold-drawn, drillable) | 1 | 5 | 4-12 | ESTIMATE |
| B | B2 | aluminium plate 3 mm (flat parts) | 2 | 6 | 25-75 | WEB + ESTIMATE |
| B | B3 | screws M2.5 x 8 DIN 7991 (flat head, steel 8.8) | 3 | 20 | 3-8 | ESTIMATE |
| B | B4 | dowel pins D3 x 6 ISO 2338 (m6, hardened steel) | 2 | 10 | 3-8 | ESTIMATE |
| B | B5 | retaining compound (Loctite 638 or 648) | 1 | 1 | 25-93 | WEB + ESTIMATE |
| B | B6 | printed parts (own printer) | 1 | 1 | 0-0 | own stock |
| B | B7 | workshop tools (if not owned) | 1 | 1 | 25-70 | ESTIMATE |
| common | C1 | socket cap screws M3 x 12 (ISO 4762, steel 8.8+) | 4 | 12 | 2-6 | ESTIMATE |
| common | C2 | bar pad screws M3 x 14 DIN 7991 (flat head) | 4 | 8 | 2-6 | ESTIMATE |
| common | C3 | heat-set inserts Ruthex M3 x 5 x 4 (bar J3 block) | 4 | 8 | 0-0 | own stock |
| common | C4 | servo extension cable, 3-pin, >= 300 mm | 1 | 2 | 6-14 | ESTIMATE |
| common | C5 | cable ties 2.5 x 100 mm | 2 | 10 | 2-4 | ESTIMATE |
| common | C6 | 6701-2RS bearings 12 x 18 x 4 (chrome steel) | 2 | 4 | 0-0 | own stock |

The full material / tolerance / finish text of every line is in the CSV column `spec_paste_ready`; `s2wrist_j3_order_list.md` holds two blocks to paste: a CNC quote request (A1, A2, with the critical dimensions: pin D11.95 +0/-0.02, flange underside flat 0.05, pin perpendicular 0.03, no anodising on pin / hub / pegs) and a metal-supplier / hardware list (B, common). Order 3 of each CNC part (2 + 1 spare).

## 6. CAN-mode offset bar (P1.2; gates G1, G5)

> **Scope**: CAN-mode lane placement is NOT validated with this hand (the lead's exact-mesh audit found collisions on every retreat pose after release, section 0 item 1). The bar, R_can and p_min below are valid for tote picks, for geometry and for insertion / lowering / release only.

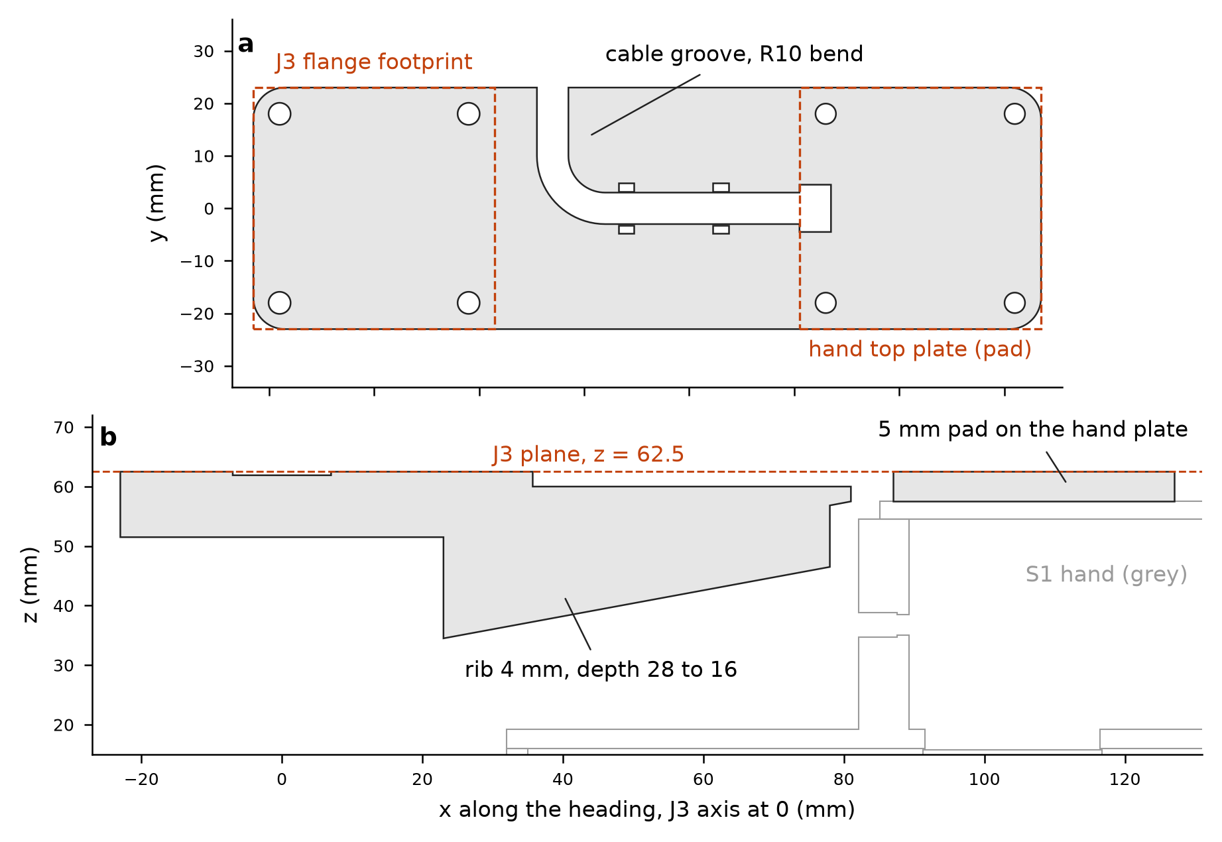
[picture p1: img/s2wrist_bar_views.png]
bar plan and side section


*a: plan section of `s2wrist_can_bar` at z = 61.25 (inside the 2.5 mm cable groove); b: side section on the centre line through the stiffening rib; grey = S1 hand body.*

### 6.1 Geometry, mass, print [s2wrist_parts_table.csv, s2wrist_bar_params.json, s2wrist_can_bar.step / .stl]

- One part, printed PETG: J3 block 11 mm thick (z 51.5-62.5) with 4 heat-set insert holes D4.2 x 9.5 on 36 x 36 (M3 x 12 from the arm flange, same 4 screws as the PET hand), tapering over x 23-45 to a 7 mm web (x 45-72), stepping to the 5.0 mm far pad (x 81-127, 46 x 46) that sits on the S1 hand top plate with 4 x 90 deg countersinks for DIN 7991 M3 x 14 flat heads into the carrier inserts. Body origin (pad datum) 104.0 mm ahead of J3; the hand hangs **5.0 mm below the J3 plane** (`z_arm = zeta_body -5.5`). Stiffening rib 4 mm wide, 28 -> 16 mm deep (x 23-78) under the web (the hand envelope under the web, x 32-80, tops out at z = 22.0 mm in the J3 frame; the rib bottom is at z >= 34.5 mm, so there is room); tie / M2.5 head relief D14 x 0.6; cable slot 6 x 9 mm in the pad over the plate notch, groove 6 x 2.5 on the top face with a **R10.0 mm bend**, 2 zip-tie slots.

- Mass **69.6 g** (solid PETG, 54782 mm3), COM 39.0 mm ahead of J3 and 5.0 mm below the J3 plane, bbox 150.0 x 46.0 x 28.0, watertight = True, estimated print **2.0 h** (0.0287 h/g, ASSUMED rate); print pose: top face (flange mating face) on the bed, flipped 180 deg about x, **no supports** (bridges <= 6 mm: groove, insert holes), 6 walls, 100 % infill; fits 250 x 250 x 255.  Hardware: 4 Ruthex M3 x 5 x 4 inserts (bar), 4 x M3 x 12 socket cap (to the J3 flange), 4 x M3 x 14 DIN 7991 flat head (to the hand), 2 zip ties, 1 servo extension >= 300 mm.

### 6.2 R_can and p_min [s2wrist_cad_rcan.csv]

R = height of the highest structure that enters the shelf tunnel above the can top, measured on the CAD (hand + bar trimmed to x >= tunnel mouth); p_min = H + L_ins 5 + T + margin 5 + R, T = 30 mm (band 20-40, ASSUMED). The bar top (the J3 plane) is the highest point in the tunnel; the hand top plate is 5.0 mm lower. A tunnel-ceiling slab touching the top gives 0 mm3 overlap and 1 mm lower gives 3084 mm3 (positive control).

| can | H mm | D mm | can top below the datum mm | R_can mm | p_min T20 | p_min T30 | p_min T40 | margin at 0.287 m | margin at 0.318 m |
|---|---|---|---|---|---|---|---|---|---|
| 355 mL can | 122.7 | 66.0 | 15.3 | 83.3 | 236.0 | 246.0 | 256.0 | 41.0 | 72.0 |
| 355 slim can | 156.0 | 57.0 | 10.0 | 78.0 | 264.0 | 274.0 | 284.0 | 13.0 | 44.0 |
| 473 mL can | 157.2 | 66.0 | 10.0 | 78.0 | 265.2 | 275.2 | 285.2 | 11.8 | 42.8 |

All three cans fit the tightest pitch (0.287 m) with 11.8 mm (473 mL), 13.0 mm (slim) and 41.0 mm (355 mL) to spare at T = 30. The 355 mL can sits lower in the grip (fingertip / floor rule z_g >= floor + 143 puts its top 15.3 mm below the datum), hence the larger R. R = 78.0 mm for the 473 mL can is below the spec's expected R of about 81 mm. This covers the arm / tunnel insertion only: the retreat after release is NOT certified for these cans (section 0, item 1).

### 6.3 Bar strength and stiffness [s2wrist_bar_checks.csv, s2wrist_bar_sections.csv]

| check | element | SF over the 3 cans (min-max) |
|---|---|---|
| B1 | bar web / rib: bending between flange edge and pad (worst section 80 mm) | 3.5-4.2 |
| B2 | hand-side: 4 x M3x14 DIN 7991 flat head (pad 5 mm + top plate 3 mm) -> carrier heat-set in | 19.7-24.3 |
| B3 | pad (5 mm): csk head pull-through | 20.6-25.3 |
| B4 | J3-end: 4 x M3x12 -> 4 heat-set inserts in the bar block (worst screw) | 6.3-7.3 |
| B5 | J3 flange / bar interface: friction torque of 4 screws vs servo limit 1.0 N*m | 3.0-3.0 |
| B8 | bar torsion web 46 x 7 (+ rib) under F = T/104 mm acting 143.5 mm below the bar | 11.2-11.2 |

Bar design variants (same 473 mL load case; s2wrist_bar_variants.csv):

| bar variant | pad mm | rib mm | mass g | B1 stress MPa (worst x = 80.5) | B1 SF | droop 1 g mm | droop 1.5 g mm | finger-tip shift 1.5 g mm |
|---|---|---|---|---|---|---|---|---|
| first draft: 3 mm pad, no rib | 3.0 | 0.0 | 60.0 | 14.37 | 1.39 | 0.615 | 0.922 | 2.89 |
| 3 mm pad + rib | 3.0 | 4.0 | 64.0 | 14.37 | 1.39 | 0.159 | 0.238 | 0.95 |
| final: 5 mm pad + rib | 5.0 | 4.0 | 69.6 | 5.68 | 3.52 | 0.117 | 0.176 | 0.58 |

Design history [s2wrist_bar_variants.csv, same 473 mL load case for all three]: the rib cuts the static droop of the pad centre from 0.922 to 0.176 mm at 1.5 g but does not help the bending at the pad step (x = 80.5, 3 mm section, cable slot): only the thicker pad does (B1 SF 1.39 -> 3.52). Final bar: droop **0.117 mm at 1 g and 0.176 mm at 1.5 g** (E(PETG) 1800 MPa ASSUMED), pad tilt shifts the finger tips by 0.58 mm at 1.5 g. Twist under the 0.3 g lateral moment: 0.0073 rad (1.0 mm at the tips). Jam at the servo limit (1.0 N*m against an obstacle at the can): bar torsion SF 11.2.

### 6.4 Cable path

Hand servo lead (stock 150 mm) -> up through the pad slot (x 81-87) -> groove along -x (40 mm straight) -> R10.0 mm bend -> out through the bar side at y = +23 (x = 34): groove length from the slot centre to the side edge **69 mm**, centre-line bend radius **10.0 mm** (rule of thumb 5 x cable OD for a 2 mm hookup cable). Add the **>= 300 mm extension**: in CAN mode the cable has to travel back 82.0 mm to the J3 axis before it joins the arm loops, a detour the S1 direct mount does not have, so the stock 150 mm lead is expected to fall short (ESTIMATE; confirm on the bench). Cable routing at J1 / J2 / J3 windows is an open S1 item (no cable design in the arm CAD).

### 6.5 Assembly order (bar)

1. Heat-set the 4 inserts into the J3 block (iron 220-230 C, same as the S1 inserts). 2. Lay the hand servo cable through the pad slot and press the pad onto the hand top plate (cable notch under the slot); fit the 4 x M3 x 14 flat heads (flush). 3. Route the cable in the groove, zip-tie. 4. Offer the bar to the J3 flange and fit the 4 x M3 x 12. 5. Plug the extension. Full mode-switch procedure in section 7.

## 7. PET <-> CAN mode-switch guide (P1.3) [s2wrist_modeswitch_steps.csv, s2wrist_modeswitch_parts.csv]

> **Scope**: the CAN mode of this guide is usable for tote picks and geometry only; CAN lane placement is not validated with this hand (section 0, item 1).

Single hand body, swap the end-effector set: **PET -> CAN 11.1 min, CAN -> PET 9.8 min** (target < 15 min; bench times ASSUMED: M3 under the housing flange 15 s out / 25 s in, other M3 8 s / 15 s, 20 s per connector or part moved, 120 s controller set-up; with a 1.5x pessimism factor 16.7 / 14.7 min). Fastener operations: 20 each way. **Dual-hand variant** (two complete hands, PET and CAN, swapped at the J3 flange): **6.2 min**, costs a second body (335 g printed, about 11 h), a second STS3215 (S1 BOM: 3 on hand) and 30 inserts.

The 4 x M3 x 12 that hold the hand to the J3 flange are the same screws in both modes (S1 BOM: M3 x 12 x 4, buy 8). The jaw interface follows the Hand track (s2hand_build.py): PET jaws replace the S1 yokes on the rack tabs (one M3 screw per jaw, assumed M3 x 8 as the S1 yoke screw), the PET guide rail bolts to 4 inserts in the base end faces (screw length not stated by the Hand track: M3 x 8 ASSUMED) and must come off in CAN mode (it occupies the S1 yoke volume).

**PET -> CAN**

| step | action | count | s |
|---|---|---|---|
| P2C-1 | Power down: J3 to the service heading, Z carriage to bench height, 12 V off | 1 | 30.0 |
| P2C-2 | Unplug the hand servo cable at the arm harness | 1 | 20.0 |
| P2C-3 | Remove the 4 x M3x12 that hold the hand to the J3 flange; lift the hand off | 4 | 60.0 |
| P2C-4 | Remove the PET guide rail (2 end brackets) from the base end-face inserts | 4 | 32.0 |
| P2C-5 | Remove PET jaws A and B from the rack tabs | 2 | 16.0 |
| P2C-6 | Fit the S1 finger sets (yoke + finger + pad, kept assembled) on the rack tabs | 2 | 30.0 |
| P2C-7 | Place the body on the bar pad (closing axis along the bar), cable through the pad slot | 1 | 20.0 |
| P2C-8 | Fit 4 x M3x14 DIN 7991 flat head through the pad into the carrier inserts | 4 | 60.0 |
| P2C-9 | Offer the bar to the J3 flange and fit 4 x M3x12 into the bar inserts | 4 | 100.0 |
| P2C-10 | Lay the cable in the groove, 2 zip ties in the bar slots; plug the 300 mm extension into the arm harness | 1 | 60.0 |
| P2C-11 | Plug the cable, select CAN mode in the controller (hand mass, L3 = 104, J3 +-90 deg heading offset, J3 torque register), power up, open/close test | 1 | 120.0 |
| handling | pick / align / put down the 6 moved parts (2 jaws, rail, body, bar, 2 finger sets, minus those not moved in this direction) | 6 | 120.0 |

**CAN -> PET**: reverse the order: remove the bar screws and body, the S1 finger sets, fit PET jaws A / B, the guide rail, offer the body to the flange rotated 90 deg, plug the stock cable, select PET mode.

Controller settings that change with the mode: hand mass (PET 0.411 kg, CAN 0.44 kg + bar 0.070 kg), J3 heading offset (use column `q3_CAN_deg` or `q3_PET_p90_deg` of s2wrist_reach_path.csv; the two differ by 90 deg), J3 torque register (section 4.6: 200 with the metal kit), `z_c = z_g + 155 mm` in CAN mode, can grasp gap for D66 = 70.35 mm / D57 = 61.03 mm (V-pads, section 9). Parts per mode:

| mode | item | qty |
|---|---|---|
| both modes | J3 flange (CNC shaft-flange / NC flange plate) + 4 x M3x12 socket cap | 4 |
| both modes | S1 hand body (base, carrier, top plate, pinion, 2 racks, STS3215, camera plate) | 1 |
| PET only | PET jaws A + B (type C collar or type F fork), 2 x M3x8 | 2 |
| PET only | PET guide rail s2hand_guide_rail + 4 x M3 (end-face inserts of s2hand_base_v2 or the drilled S1 base) | 1 |
| CAN only | s2wrist_can_bar (printed PETG, 4 Ruthex M3x5x4 inserts in the J3 block) | 1 |
| CAN only | 4 x DIN 7991 M3x14 flat head (bar pad -> carrier inserts) | 4 |
| CAN only | S1 finger sets: 2 x yoke + finger + TPU pad, 2 x M3x8 | 2 |
| CAN only | Feetech 3-pin servo extension >= 300 mm, 2 zip ties | 1 |

## 8. Reach table with the new datums (P1.4) [s2wrist_reach_summary.csv, s2wrist_reach_path.csv, s2wrist_reach_tote_approach.csv, s2wrist_reach_outside_limits.csv]

y_E = 330 (lane-entrance datum), y_front = 313, lane length 250, L3 = 104 (bore / pad datum ahead of J3), place target y_bore = 330 + D/2 + 1.5, straight insertion along +y from outside the divider noses, analytic IK on both elbow branches, wrapped into the J1 window; limits J1 [-20, 160], J2 +-130, J3 +-180 deg, r [170, 385] mm. Rows for the used branch q2 > 0; D 65 / 71 bracket the CAN cans (D66 / D57 give y_bore 364.5 / 360, inside the tabulated range of y).

| lane x mm | D mm | whole path ok | r_min | r_max | place J3 y | q1 deg | q2 deg | q3 CAN deg | strap-to-y_front margin mm (PET) |
|---|---|---|---|---|---|---|---|---|---|
| x-152 | 65.0 | True | 242.2 | 301.2 | 260.0 | 79.2 | 82.3 | -71.5 | 22.9 |
| x-76 | 65.0 | True | 203.2 | 270.9 | 260.0 | 58.9 | 94.8 | -63.7 | 22.9 |
| x+0 | 65.0 | True | 188.5 | 260.0 | 260.0 | 40.5 | 98.9 | -49.5 | 22.9 |
| x+76 | 65.0 | True | 203.2 | 270.9 | 260.0 | 26.3 | 94.8 | -31.1 | 22.9 |
| x+152 | 65.0 | True | 242.2 | 301.2 | 260.0 | 18.5 | 82.3 | -10.8 | 22.9 |
| x-152 | 71.0 | True | 239.8 | 303.8 | 263.0 | 79.4 | 81.2 | -70.6 | 19.9 |
| x-76 | 71.0 | True | 200.5 | 273.8 | 263.0 | 59.3 | 93.6 | -62.9 | 19.9 |
| x+0 | 71.0 | True | 185.5 | 263.0 | 263.0 | 41.1 | 97.8 | -48.9 | 19.9 |
| x+76 | 71.0 | True | 200.5 | 273.8 | 263.0 | 27.1 | 93.6 | -30.7 | 19.9 |
| x+152 | 71.0 | True | 239.8 | 303.8 | 263.0 | 19.4 | 81.2 | -10.6 | 19.9 |

The q2 > 0 branch is feasible over the whole path for every lane and D. The q2 < 0 branch violates J1 <= 160 deg for lanes x = -152 and -76 (first violation q1 = -178.4 / 171.4 deg at s = 0); lanes x >= 0 are feasible on both branches. J3 radius along all lane paths: min 185.5 mm (x = 0, D71), max 303.8 mm. J3 y at the place pose 260.0-263.0 mm.

Tote (pockets y = 0 / 100 / 200 at x = -300, J3 at x = -196): final poses feasible on q2 > 0 only; the straight -x approach is limited to 26.0 / 58.5 / 120.0 mm for y = 0 / 100 / 200 (D75 bottle datum); the lead accepted a vertical drop-over (lift, then lower into the pocket). Pocket y = -100 is optional and J3 y < 0 is not covered by the S1 arm sweep; y = 300 is feasible with a 120 mm straight approach.

## 9. Geometry gate G1 for the wrist / bar part [s2wrist_cad_interference.csv, s2wrist_cad_world_headings.csv, s2wrist_cad_world_summary.csv, s2wrist_cad_world_controls.csv]

**Not covered here: the retreat after release.** The lead's exact-mesh audit of the CAN-mode meshes found collisions on all later retreat poses (section 0, item 1). The results below (every used heading free, zero overlaps) concern the arm / J3 stack / pedestal / column environment and the insertion, lowering and release poses, not the lane retreat.

manifold3d booleans, criterion 1 mm3, every family with a deliberate positive control. **44 tests, 0 failed; largest overlap among the real tests 0.000 mm3; smallest overlap among the 13 positive controls 44.2 mm3 (all detected).** Families: F1 hand-bar, F2 bar / hand vs J3 stack + L2 (S1 chain, CNC kit, NC kit), F3 kit parts vs housing / bearings / spacer / L2 / servo / horn / shims, F4 rotating group (hand at finger gaps 40 / 70 / 125 + bar + J3 rotor) vs the static stack at q3 = -180..165 step 15, F5 cans in the grip (contact gap bisection on the V pads: D66 -> 70.35 mm, D57 -> 61.03 mm; every other hand part clear). Minimum vertical clearance of hand + bar under the static stack 3.30 mm (bar top 62.5 to the housing bottom 65.8).

CAN-mode hand extents in the J3 frame (xmin, ymin, zmin, xmax, ymax, zmax): gap 70 [32.0, -30.1, -145.5, 176.0, 30.1, 57.5]; gap 125 (open) [30.0, -30.1, -145.5, 178.0, 30.1, 57.5]; bar [-23.0, -23.0, 34.5, 127.0, 23.0, 62.5]. In a 76 mm pitch lane with 3 mm dividers (73 mm clear width) the hand's widest part (yoke straps, |y| = 30.10 mm) clears the dividers by 6.40 mm per side; the fingers (|y| 22.2 mm) by 14.3 mm. The full rack mock-up (dividers, shelf plate, neighbouring cans, tote) is NOT run here.

World sweeps: hand + bar (gap 70 and 125) at 5 lane place poses and starts and 5 tote poses, all headings in 5 deg steps, against the J1 pedestal, clamp, J1 servo, Z carriage plate, column and rail. **Every used heading is free** (lane +90 deg, tote 180 deg, both finger gaps). Forbidden heading arcs (gap 125, deg from +x): lane x = 0 start pose 260..280; tote y = 0 285..305; tote y = -100 0..5;310..355; all other poses none. Controls: 3 of 3 deliberate collisions detected.

## 10. P2 - stiffer J3 servo retention (assessment, no CAD)

With either kit the servo no longer carries the moment: the pin / rod runs in the two 6701 inside the housing, which is bolted to the L2 floor (C9a SF >= 2.43 at 2 L), so the shaft sees torque and the weight only. Upward loads (a jammed bottle on the Z lift) go hub shoulder -> lower 6701 -> spacer -> upper 6701 -> L2 floor, not the servo. The worthwhile change is process: bond the two inner races to the pin / rod with retaining compound (also for the CNC kit) so the weight bypasses the POM horn threads; no part changes. A stiffer servo pocket would add TPU shims only (the pocket walls are too thin for inserts) and was not drawn. A COTS 25T steel / Al horn exists (a steel 25T horn at justcuzrobotics.com/products/ssp-servo-horn, 6.7 g, reported to fit a Feetech servo) but its hole pattern against the S1 10 x 10 pattern is UNVERIFIED, so it is not in the order list.

## 11. Open risks and assumptions

1. 6701 material unknown (chrome / stainless): decides whether 1 L is allowed (stainless: SF 1.33 at 1 L). 2. NC kit depends on rod squareness, thread depth and bond quality; proof test mandatory; unknown aluminium alloy invalidates N2. 3. POM horn threads UNASSESSED. 4. STS3215 shaft rating unknown. 5. Sim peaks (3.16 / 3.89 N*m) unverified: if they are real and repeated, 6061 and the NC plate are marginal (section 4.5). 6. Hand mass / COM are first-CAD values. 7. Droop and twist use E = 1800 MPa ASSUMED; the bar prints 100 % infill, 6 walls. 8. Bench times in section 7 are ASSUMED; the PET guide-rail screw length is ASSUMED. 9. Cable routing along the arm is not designed (S1 open item); CAN mode needs the >= 300 mm extension. 10. Prices are estimates / listings, not quotes. 11. Tolerance stack: the bar's 4 inserts and the pad holes are printed (D3.4 clearance, D4.2 insert holes): expect +-0.2 mm hand position; calibrate with the vision loop.

12. **CAN lane placement NOT validated (the retreat collides, section 0, item 1) - what would remove it** (not designed or checked by this track; no new CAD was made for it). (a) Jaws that hold a can at the rim or the seam collar instead of the body, mounted on the same S1 body and rail: the front jaw would then end above the can shoulder, so the lift needed after release is about the jaw depth instead of the can height and fits in the 20-80 mm available under the tunnel ceiling (my inference, unchecked). (b) Lane geometry that opens the front, so the front finger can leave without lifting over the can. (c) A taller tunnel: according to the lead's audit only p = 0.381 m with the 355 mL can has a lift window (130-140 mm), which is not the product pitch. A J3 rotation cannot help: the finger plates are 52 mm wide in a 73 mm lane (lead's audit; my extents: slider group y span 52.3 mm, yoke straps |y| = 30.15 mm, section 9). Tote picks and the offset bar itself are not affected.

## 12. Interface notes for the other tracks

- **Lead**: CAN lane placement is NOT validated with this hand (retreat collisions, section 0 item 1; remedies in section 11 item 12). Bar pad 5 mm (not 3): hand drops 5.0 mm below the J3 plane, R_can 78.0 / 83.3 mm, p_min(473 mL) 275.2 mm, `z_c = z_g + 155 mm` in CAN mode; moving mass in CAN mode 0.44 kg hand + 0.070 kg bar + can; torque register 200 with the metal kit (130 with the printed chain); moment-at-SF-2 table and the SF calculator for the Sim peaks (section 4.3 / 4.5).

- **Sim**: CAN-mode transform body -> J3 frame (x + 104, z -5.5); can grasp gap for D66 = 70.35 mm, D57 = 61.03 mm (V pads with 1 mm ribs); the J3 torque register / limit; the tilt of the bar under load (0.23 deg at 1.5 g) is not in the rigid-body model; use `sf_at()` on the logged (Mh, Fz) peaks. **Exact meshes for placement**: `s2wrist_can_mode_*_j3frame.stl` + `s2wrist_can_mode_interface.json` (J3 frame, transform to the arm frame, finger-slider rule, COM and mass per can; section 14).

- **Rack**: R_can and p_min per can (section 6.2; insertion only, the retreat is not certified, section 0 item 1); the hand in CAN mode closes along the heading, so the next can in the lane must leave the bay (S1 bay rule; recompute for 250 mm lanes); hand extents and used headings in section 9; place poses in s2wrist_reach_path.csv.

- **Hand**: CAN mode needs the PET guide rail and PET jaws removed (the rail occupies the S1 yoke volume); please confirm the jaw screw (M3 x 8?) and the rail screw length; the 4 x M3 x 12 flange screws are shared; the hand cable needs a >= 300 mm extension in CAN mode.

- **Check**: `s2wrist_cadlib.py` + `s2wrist_cadcheck.py` give the frames, loaders and boolean helpers (J3 frame, hand at any finger gap, the three J3 options); positive controls are part of every family.

## 13. How to re-run

`bash s2wrist_run_all.sh` (about 8 min, env `robodesign`) regenerates the bar / kit CAD, all CSVs and the CAD checks in dependency order; and finally runs the order list, the mode-switch guide, the DXF export, the CAN-mode mesh export and this README generator (`python s2wrist_make_readme.py` alone rebuilds only this file). Inputs expected in `./in` (arm / gripper / zmod STEP, spec_v4.txt, S1 BOM) and `./out`.

## 14. CAN-mode meshes and placement data for exact-mesh audits [s2wrist_can_mode_*_j3frame.stl, s2wrist_can_mode_interface.json]

**Status**: the lead's exact-mesh audit with these meshes found no collision on insert / lower / release but collisions on every later retreat pose (section 0, item 1): use them for retreat and lift-over studies, not as a certificate.

All meshes are in the **J3 frame**: origin on the J3 axis, z = arm zeta (J3 interface plane z = 62.5), +x = heading, +y lateral. To place them in the arm frame: `[x_w, y_w] = [px, py] + R(psi) [x', y']`, z unchanged, with the J3 position (px, py) and heading psi taken from s2wrist_reach_path.csv (lanes psi = +90 deg, tote picks psi = 180 deg; J3 heading = psi, the CAN-mode q3 is in column `q3_CAN_deg`). Carriage height: `z_world = z_c + z_arm - 149.5` (z_c = J1 horn plane; the hand datum sits at arm z = -0.5 - 5.0 mm, so z_c = z_g + 155 mm in CAN mode).

| part | STL | bounds min (x, y, z) mm | bounds max (x, y, z) mm | watertight (union of the solids) | volume mm3 |
|---|---|---|---|---|---|
| hand_static | s2wrist_can_mode_hand_static_j3frame.stl | 32.0, -29.1, -9.3 | 176.0, 29.1, 57.5 | True | 174227.8 |
| hand_slider_plus | s2wrist_can_mode_hand_slider_plus_j3frame.stl | 69.5, -22.1, -145.5 | 150.5, 30.1, 21.9 | True | 78134.0 |
| hand_slider_minus | s2wrist_can_mode_hand_slider_minus_j3frame.stl | 57.5, -30.1, -145.5 | 138.5, 22.1, 21.9 | True | 78134.1 |
| bar | s2wrist_can_mode_bar_j3frame.stl | -23.0, -23.0, 34.5 | 127.0, 23.0, 62.5 | True | 54782.1 (bar_params) |

Hand: S1 body frame -> J3 frame = translate (104.0, 0, -5.5) mm. The two finger sliders (rack + yoke + finger + pad) are separate meshes at pad gap 70 mm (apex to apex): for a pad gap g translate `slider_plus` by +(g - 70)/2 and `slider_minus` by -(g - 70)/2 along x' (in CAN mode the fingers close along the heading, x'; the y bounds of the two sliders only show which side of the pinion each rack sits on: rack A at +y, rack B at -y). Contact gap for a can of diameter D: g = D sqrt(1 + 0.27^2) + 2.0 mm.  Masses: hand 0.44 kg as designed (printed only 0.3355 kg), bar 0.0696 kg.  COM in the J3 frame (x, y, z) mm: hand (110.79, 0.00, -4.36), bar (39.05, 0.00, 57.47).

| can | D mm | H mm | can kg | top below datum mm | can top z (J3 frame) | can bottom z | pad gap at contact mm | hand + bar + can kg | COM of all three (x, y, z) mm |
|---|---|---|---|---|---|---|---|---|---|
| 355 mL can | 66.0 | 122.7 | 0.382 | 15.3 | -20.8 | -143.5 | 70.36 | 0.8916 | 102.28, 0.00, -32.86 |
| 355 slim can | 57.0 | 156.0 | 0.382 | 10.0 | -15.5 | -171.5 | 61.04 | 0.8916 | 102.28, 0.00, -37.72 |
| 473 mL can | 66.0 | 157.2 | 0.507 | 10.0 | -15.5 | -172.7 | 70.36 | 1.0166 | 102.49, 0.00, -44.88 |

The can axis is at (x', y') = (104, 0) in the J3 frame. The same JSON lists the tunnel heights R_can and the file names; the S1 / CNC / NC J3 kit parts are in the J3 frame in their STEP files and do not move with the mode.

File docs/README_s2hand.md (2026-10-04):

# S2 PET-mode hand: collar jaws on the S1 gripper body (HAND track, S2-RC2)

Frame used everywhere: x = closing axis (jaw A on +x, jaw B on -x), y = heading (+y toward the bottle), z = zeta (up, origin on the J3 / pinion axis); seat plane (ring underside of a seated bottle = lip top) at zeta0 = -12.3 mm, z' = zeta - zeta0. All lengths mm. Every number below was produced by code in this session (scripts and CSV sources are linked in section 13); items marked ASSUMED are not measured.

**Where the LEAD requests are answered**: A assembled-frame meshes + manifest -> sections 4 and 13 (hard-stop pose, groups, masses, pinion rotation); B tilt envelope + fix -> section 8; C friction budget / hold table -> section 7; D assembly, torque register, print list, Gate-0 order -> sections 1-3; E lip ramp, lip friction, BACK_CLR -> section 9; Gate-0 slot gauges -> section 1b and 5.7; short-neck jaws and the free-neck rule -> sections 5 and 9.4; strength, droop and maximum mass -> section 6; P2 -> section 10.

## 0. Deviations, corrections and items NOT assessed (read first)

| # | Item | Status | What it means |
|---|---|---|---|
| 1 | Bore style | DEVIATION from the master spec (accepted by LEAD) | The spec asks for stepped CIRCULAR half-bores. They cannot clamp the cap-OD box: the jaws stop at 2.2 / 4.3 / 6.4 mm per jaw for caps 29.5 / 30.5 / 32.0 (flat faces: 0.25 / 0.75 / 1.50), contact is only at the arc end edges and the lip circles move out with the jaws (ring seat collapses). The delivered main jaw uses stepped PLANAR faces (BORE_STYLE "flat"); "circ" is only a build option. Evidence: s2hand_bore_style_study.csv. |
| 2 | Seat plane | CHOSEN | zeta0 = -12.3 (spec relation assumed -4.3); rule z_c = z_ring_underside + 162.3 mm (accepted by LEAD). |
| 3 | GROOVE_H, BACK_CLR | CHOSEN | GROOVE_H = 5.5 (spec range 3.5-5.5, nominal 4.5: 5.5 gives 121/129 corners for a release lowering of D = 2 mm and 113/129 for closing at the 2.2 mm window, instead of 77/129 and 73/129 with 4.5; per-corner scan in s2hand_groove_height_scan.csv, earlier build state, the final-geometry scan [s2hand_bottle_scan_flat_CF.csv](s2hand_bottle_scan_flat_CF.csv) reproduces 121 / 113 for 5.5), BACK_CLR = 4.0 (back wall y = 83, Sim request; spec 1.0). |
| 4 | Jaw width | DEVIATION | Jaw bars are 22-23 mm wide, not 5-6 mm plates (a 5 x 22 mm plate 78-130 mm long would deflect 10-40 mm sideways at 25 N). |
| 5 | Guide | DEVIATION / proposal adopted | Guide = front rail (part s2hand_guide_rail, 4 mm L-brackets on 4 M3 inserts in the base END FACES x = +-72, y = +-12, z = 1) + base bottom as rear stop, instead of a beam under the base. The S1 base needs 4 holes D4.2 x 5.5: drill template (2 x ~0.4 h) or reprint s2hand_base_v2 (2.4 h model). |
| 6 | G3 droop (1.2 kg x 1.5 g, <= 1.0 mm; L/R <= 0.5 mm) | MET ONLY WITH THE PTFE/SHIM ASSEMBLY STEP | Elastic droop (FE jaw + rail flexure through the guide lever) = 0.40 mm (A) / 0.37 mm (B), L/R difference 0.028 mm. But the printed 0.2 / 0.2 mm guide gaps close under the nose-heavy jaw: nose shift 0.79 / 0.77 mm (not elastic) -> total 1.19 / 1.14 mm FAILS 1.0 mm. With gaps reduced to <= 0.12 mm (0.08 mm PTFE tape on rail top and bar tops, feeler-check) the total is 0.88 / 0.83 mm. L/R difference is deterministic 0.05 mm but +-0.4 mm if the two printed gaps differ by 0.1 mm each: MUST be feeler-checked at first assembly (not assessed on hardware). 2 L x 1.5 g: 1.19 mm (stretch SKU, fails). |
| 7 | Jaw clamp-path FE | CORRECTED | The earlier clamp / stall FE runs (across-layer SF 1.63, deflection 1.06 mm) had NO tab-wall support because of a node-mask bug; superseded. Corrected 1.5 mm voxel FE: clamp 25 N across-layer peak 2.67 MPa B / 2.46 MPa A (SF 3.75 / 4.07), lateral stiffness k = 34.2 (B) / 42.2 (A) N/mm. Stall (100 N, single event, S1 single-event allowables 35 / 17.5 MPa): SF 1.64 (B) / 1.78 (A) across layers, 1.9 / 2.2 in-plane excluding load/support elements. Repeated stall is not allowed; keep Max_Torque_Limit <= 400. 1.0 mm voxel check of the corrected code (row 17, [s2hand_fe_clamp_convergence.csv](s2hand_fe_clamp_convergence.csv)): clamp 25 N across-layer peak excluding contact elements 3.39 MPa B / 2.93 MPa A (SF 2.95 / 3.42), in-plane SF 3.24 / 4.34, k = 32.4 (B) / 49.7 (A) N/mm; stall (linear scaling x 4 of the 25 N case): SF 1.29 (B) / 1.50 (A) across layers, 1.42 / 1.90 in-plane. The 1.0 mm values are the lowest of the three meshes and are the ones to use. |
| 8 | Clamp force vs cap OD | NEW FINDING | Because of the jaw lateral compliance the clamp force on small caps is limited by the hard stop: F = 18.9 N/mm x (OD - 29.0) for OD < 30.3 mm at TQ 0.70 (9.4 N at 29.5, 18.9 N at 30.0); full 24.8 N only for OD >= 30.3 mm. Servo ticks read the hard stop for OD <= 30.3, so cap OD cannot be inferred from ticks below that (section 3). |
| 9 | Friction-only carry | LIMITED | With PETG faces (ASSUMED mu 0.3-0.5) friction alone holds only 500 / 600 mL at SF >= 2 (static, 25 N per jaw); 1 L needs mu >= 0.5; 1.5 L and 2 L need the lip. The 1.2 kg design mass is lip-supported. |
| 10 | Swing about the closing axis (LEAD item B) | NOT MET passively | Flat faces give no restoring torque: free swing is -14...-34 deg / +7...+40 deg (40 corner combinations), a shallow V adds only 55-93 N mm and costs seat width. Verdict and the cheapest fix (TPU pad pocket + transport torque + acceleration limits) are in section 8; +-8 deg at 0.3 g lateral is met only for 500 / 600 mL without changes. |
| 11 | Type F | PARTIAL | F-type = same jaws without the cap wall (groove face to the top). Approach / drop-over 129/129 corners, release D=1/2/3: 129/97/81. The scan flags seated_ok / close_ok of the C-type scan are not meaningful for F (the fork has no cap wall to stop on), so an F-specific closing check was run afterwards ([s2hand_F_close_check.csv](s2hand_F_close_check.csv), script s2hand_verify_F_close.py): for each of the 129 corners the jaws are swept from the open pose (delta 10 mm) to the hard stop in 0.5 mm steps with the lip top 0.2 / 1.2 / 2.2 mm below the ring underside (overlap criterion 1 mm3). 129 / 97 / 81 corners reach the hard stop without touching the bottle. Every failure is a free-neck 3.0 mm corner (the lip meets the shoulder cone; overlap 2.94-4.33 mm3 at the 1.2 mm window, 1.15-20.17 mm3 at the 2.2 mm window); all 65 corners with free neck >= 6 mm pass at all three windows, i.e. the same free-neck rule as for C. Positive controls (s2hand_F_close_check_controls.csv): neck OD 27.5 at the stop 14.37 mm3, jaws 0.5 mm past the stop on a 26.5 mm neck 14.12 mm3, ring OD 35 at the stop 10.73 mm3 (all detected). F seat geometry (hard stop, ring on the lip): ring bearing width 2.75-3.75 mm (nominal 3.25), neck-to-lip clearance 0.0-1.0 mm (nominal 0.5), no lateral clamp. FE of the F jaws was NOT run (C jaws only). Mass 396.9 g. |
| 12 | lip2 jaws | FE COMPLETE at 1.0 mm (stall by scaling) | Boolean fit scan done (216 corners). FE at 1.0 mm voxel, corrected code, both jaws: lip hold 8.8 N: deflection 0.2123 (A) / 0.2141 (B) mm, SF 9.8 / 9.7 in-plane, 11.1 / 11.0 across-layer (s2hand_fe_lip2_d1p0.csv, s2hand_fe_lip2_B_d1p0.csv); clamp 25 N: cap-face deflection 0.516 (A) / 0.786 (B) mm, across-layer SF excluding contact elements 3.42 / 2.95, in-plane 4.35 / 3.24 (A, B); the lip relief does not change the clamp path (baseline 1.0 mm values: 0.503 / 0.772 mm, 3.42 / 2.95). The clamp row first saved in s2hand_fe_lip2_d1p0.csv (jaw A, 25 N: 0.7456 mm, across-layer SF 1.88) is INVALID - it came from a job started before the tab-wall support fix - and is flagged valid = False in the current version. The thinner-lip ledge beam estimate remains the governing number for the lip (SF 1.7 for 2 L x 1.5 g, 3.0 at 1.2 kg x 1.5 g). |
| 13 | Gauge labels | CHANGED | Engraved text made the exported STL non-watertight; gauges are identified by 1 / 2 / 3 / 4 notches in the bridge top edge. |
| 14 | Servo register addresses | VERIFY | Torque_Limit (RAM, addr 48 / 0x30, 0-1000 = 0-100 % of 2.942 N m stall), Max_Torque_Limit (EEPROM, addr 16 / 0x10) are from the Feetech STS3215 table as I remember it; confirm in test B2 before relying on them. |
| 15 | Mass / COM CSV | FIXED | The earlier message claimed s2hand_* files were saved before [s2hand_mass_com.csv](s2hand_mass_com.csv) existed (auditor finding). It is saved now: type C 398.4 g, type F 396.9 g (final geometry; the first-CAD report was 399.4 g). The Wrist track used the first-CAD values 399.4 g / COM y 11.1 mm; final 398.4 g / 10.78 mm: difference 1.0 g (0.25 %) and 0.32 mm, i.e. 1.36 N mm of gravity moment about the J3 axis for the y offset; LEAD treats it as immaterial and the HAND track does not object. |
| 16 | Not assessed | - | Real friction coefficients (no test data), printed-gap tolerance, creep / fatigue of PETG under the continuous hang load, thermal drift, camera plate (optional, +11.7 g, not designed in), Al-strip reinforcement (not needed by the FE stresses), servo thermal limit at 0.70-1.0 N m holding, FE of the F jaws, rail unilateral-contact effect on the droop (+20 % deflection estimate not simulated). |
| 17 | Clamp-case FE | CORRECTED, MESH CHECK DONE (1.5 / 1.25 / 1.0 mm) | An earlier set of clamp / stall runs had no x-support at the tab wall (voxel node-plane mask bug); every clamp / stall value in section 6 is from the corrected code (30 wall nodes at 1.5 mm, 42 at 1.25 mm, 63 at 1.0 mm). Mesh check, clamp 25 N ([s2hand_fe_clamp_convergence.csv](s2hand_fe_clamp_convergence.csv); raw: 1.5 mm, A 1.25 mm, A 1.0 mm, B 1.0 mm; script s2hand_fe_clamp_buf.py): jaw A at 1.5 / 1.25 / 1.0 mm: cap-face deflection 0.592 / 0.516 / 0.503 mm (k = 42.2 / 48.4 / 49.7 N/mm); peak excluding contact elements in-plane 3.92 / 4.17 / 4.61 MPa, across-layer 2.456 / 2.796 / 2.926 MPa; peak at >= 3 mm from every load / support node in-plane 3.10 / 3.13 / 3.59 MPa, across-layer 1.94 / 1.80 / 2.21 MPa. Jaw B at 1.5 / 1.0 mm: deflection 0.732 / 0.772 mm (k = 34.2 / 32.4 N/mm), in-plane 4.61 / 6.18 MPa, across-layer 2.668 / 3.394 MPa. The 'excluding' peaks grow 18-34 % from 1.5 to 1.0 mm (slow approach to the support singularities), the deflection changes -15 % (A) / +6 % (B), the series stiffness goes 18.9 -> 19.6 N/mm (+4 %, clamp-force table unchanged). Lowest clamp-path safety factors at the 1.0 mm mesh (across layers, 10 MPa allowable): 2.95 (B) at 25 N, 2.08 (B) at the 1.0 N m transport torque (35.4 N), 1.77 (B) at 1.177 N m (41.7 N); stall 100 N (single event, linear scaling): 1.29 (B) / 1.50 (A). Not resolved: the sharp inner corner of the tab window (no fillet; the 0.4 mm window clearance limits any fillet to R <= 0.6-0.8 mm). |
| 18 | Timeline | NOTE | README v1 was saved on 2026-10-03 about 07:55 UTC, before the 08:45 UTC deadline. The session was then suspended and resumed on 2026-10-04 08:03 UTC (new LEAD deadline 10:30 UTC). This version contains the late additions: F-type closing check (row 11), FE mesh check and lip2 FE completion (rows 12 / 17), groove-height scan CSV (row 3), servo-table notes updated to the 1.0 mm FE (section 3). |

## 1. Print order for the Gate-0 hand test

Print settings (PETG, STL/STEP are already in print pose, no supports, do not re-orient or scale): 0.2 mm layers, 0.4 nozzle, >= 4 perimeters, 25-30 % gyroid (gauges: 3 perimeters, 15 %), dry filament. Hours = project model 0.25 h + mass / 33 g/h (the slicer will differ).

| step | part | qty | mass_g | hours_model | purpose |
|---|---|---|---|---|---|
| 1 | s2hand_gauge_cap30p5 | 1 | 12.9 | 0.64 | nominal cap 30.5 mm slot gauge; try every real bottle on it first |
| 2 | s2hand_gauge_cap29p5 | 1 | 12.8 | 0.64 | cap 29.5 mm position |
| 2 | s2hand_gauge_cap32p0 | 1 | 13.0 | 0.64 | cap 32.0 mm position |
| 3 | s2hand_gauge_cap30p5_lip2 | 1 | 12.1 | 0.62 | only if a bottle has free neck 3.0-4.0 mm (2.0 mm lip) |
| 4 | s2hand_stick_A_C | 1 | 17.2 | 0.77 | hand-held clip stick (jaw A head): jaw half with the real lip / groove / cap faces, lead-ins and ramp |
| 4 | s2hand_stick_B_C | 1 | 17.2 | 0.77 | clip stick, jaw B head |
| 5 | s2hand_drill_template | 2 | 5.2 | 0.41 | only if the S1 base is already printed: drill the 4 end-face holes (D4.3 guides), then heat-set 4 M3 inserts |
| 6 | s2hand_guide_rail | 1 | 44.4 | 1.60 | rail + brackets |
| 7 | s2hand_jaw_A_C | 1 | 37.1 | 1.37 | jaw A (type C) |
| 7 | s2hand_jaw_B_C | 1 | 40.4 | 1.47 | jaw B (type C) |
| 8 opt | s2hand_jaw_A_C_pad | 1 | 37.1 | 1.38 | jaw A with 1 mm pad pocket (use with s2hand_pad_tpu, TPU 95A) |
| 8 opt | s2hand_jaw_B_C_pad | 1 | 40.4 | 1.47 | jaw B with pad pocket |
| 8 opt | s2hand_pad_tpu | 2 | 0.2 | 0.26 | TPU strips 14 x 10.5 x 1.0 (print 4) |
| 8 opt | s2hand_jaw_A_C_lip2 | 1 | 36.5 | 1.36 | short-neck set (2.0 mm lip), replaces jaw A |
| 8 opt | s2hand_jaw_B_C_lip2 | 1 | 39.8 | 1.46 | short-neck set, replaces jaw B |
| 9 opt | s2hand_stick_A_F | 1 | 16.4 | 0.75 | type F clip stick (only if the fork type is evaluated) |
| 9 opt | s2hand_stick_B_F | 1 | 16.4 | 0.75 | type F clip stick |
| 9 opt | s2hand_jaw_A_F | 1 | 36.3 | 1.35 | type F jaw A |
| 9 opt | s2hand_jaw_B_F | 1 | 39.6 | 1.45 | type F jaw B |
| 9 opt | s2hand_base_v2 | 1 | 72.3 | 2.44 | S1 base with the 4 holes (instead of the drill template) |

Gate-0 sequence: (1) the three slot gauges (about 25 min of extrusion each) answer "ring enters the groove / lip passes under the ring / cap sits on the faces" for the real bottles before any jaw is printed; (2) the two clip sticks (~0.8 h each) are the same head geometry as the jaws and let you push-test ring, lip, ramp and lead-ins by hand; (3) only then the drill template, rail and the two jaws (total 4.4 h). The 8 tolerance-ladder head pairs (s2hand_ladder_*.stl, ~0.8 h each) are only needed if a gauge fails: LIP_T 2/3/4/5, GROOVE_H 3.5/4.5/5.5, D_CAP_HS 28/29/30 (one factor at a time, L+R side by side).

Post-processing: remove elephant foot / stringing from the slot faces with a scraper (do not sand the cap-wall or lip faces: they set the 0.25 mm steps); ream the two M3 holes of each strap to 3.2; check the strap window on the rack tab (0.2 mm closing-side clearance, 0.4 mm vertical) and relieve with a needle file if tight; optional: 600-grit on the lip TOP plane only (lower friction, section 9); PTFE tape (0.08-0.1 mm adhesive film) on the rail top (2 patches 24 x 8) and on the bar tops (2 x 20 x 20) to bring the guide gaps to <= 0.12 mm.

## 1b. Gate-0 slot gauges: use note

**Use note (one paragraph)**: each gauge is the two jaw slot profiles (lip, groove and cap-wall steps, back wall at y = 83, 45 deg lead-ins, lip ramp) cut from a 20 mm slab and joined by a 4 mm back bridge at the face spacing of one cap-OD position (jaw displacement 0.25 / 0.75 / 1.50 mm = cap 29.5 / 30.5 / 32.0 mm; the lip / cap-wall / groove face gaps are 27.0 / 29.5 / 34.5, 28.0 / 30.5 / 35.5 and 29.5 / 32.0 / 37.0 mm; the lip2 gauge is the 30.5 position with a 2.0 mm lip). The notches in the top edge of the bridge count 1 / 2 / 3 / 4 (cap 29.5 / 30.5 / 32.0 / 30.5-lip2); in use the notched edge is the TOP, the part is printed lying on its back. Hold the gauge level, slot opening toward the bottle, push it onto the neck from the front about 1-2 mm below the final height until the cap approaches the back wall, then lift until the ring underside rests on the lip. **Good**: the cap sits between the cap-wall faces touching (or with a hair of play) for the gauge whose OD matches it, and with about 0.25 mm per side of visible gap for a cap 0.5 mm smaller; the ring lies in the groove with air above and beside it (groove 5.5 mm high, 34.5-37 mm wide); the lip tip is under the ring and the ring rests on it; the bottle hangs from the lip; the cap top stands about 1 mm ABOVE the jaw top for the nominal 18 mm cap (master spec: the jaw top z' = 17 is 1 mm below the cap top; a cap shorter than 17 mm ends below the jaw top and is also fine). **Failures and their meaning**: the cap does not enter the faces -> cap OD is larger than this gauge, use the next gauge (boolean: +0.6 mm = 26-27 mm3 overlap); the ring does not enter the groove or stops on the lead-in -> ring OD above the groove gap minus 0.5 mm or ring thicker than 5.5 mm (14 mm3 / 9-59 mm3); the gauge cannot be lifted to the ring because the lip does not pass under it -> free neck too short for the 3.0 mm lip, use the lip2 gauge (needs free neck >= 3.0 mm at a release lowering of 2 mm, >= 1.6 mm just to close at 0.2 mm above the seat); the neck wedges against the lip faces -> neck OD larger than the lip face gap (27.0 / 28.0 / 29.5 mm). All 49 boolean cases (nominal pass, tolerance extremes pass, controls fail) are in the gauge checks CSV.

## 2. Assembly sequence, hardware, delta against the v1 gripper

1. Base end faces: drill / print the 4 holes (D4.2 x 5.5 at x = +-72, y = +-12, z = +1; wall >= 2.7 mm, boolean-checked) and heat-set 4 inserts M3 x 5 (Ruthex-type). Skip if base_v2 is used (inserts are still needed).
2. Remove the v1 fingers, yokes and TPU pads from racks A and B (frees 12 M3 screws + 12 inserts).
3. Slide jaw A onto the tab of rack A from the OUTER +x side (strap on the +y flank, window open to the outside), jaw B onto rack B from -x (strap on the -y flank). Fit the vertical retention screw M3 x 8 into the tab insert with a 0.5 mm washer / shim under the head so that the strap floats +-0.4 mm vertically.
4. Offer the guide rail from below: bar tops pass between the base bottom and the rail (0.2 / 0.2 mm design gaps); bolt the two L-brackets to the 4 end-face inserts with 4 x M3 x 10. Check both gaps with a feeler gauge; tape with PTFE until both are <= 0.12 mm and the jaws still slide by hand over the full travel.
5. Set the grip servo (section 3): EEPROM Max_Torque_Limit 400, RAM Torque_Limit 238; drive to the closed hard stop with Torque_Limit 119 (0.35 N m) and set the zero offset so that it reads -122.2 ticks from the mechanical zero (1925.8 with a 2048 mid-range zero); then check the recommended open position (+421.0 / 2469.0) and the open hard stop (+2363.1 / 4411.1 - never command beyond).
6. Fit-check with the gauge-matched bottle: the cap must sit on the cap faces with the ring in the groove and the lip under the ring at closing; repeat the bottle on the clip sticks if the jaws disagree with the gauge.

Hardware per hand: 4 heat-set inserts M3, 4 x M3 x 10, 2 x M3 x 8 + 2 washers 0.5 mm (retention; reuse the v1 yoke screws), PTFE tape, optional TPU pads (4). Removed from v1: 2 yokes, 2 fingers, 2 TPU pads, 12 M3 + 12 inserts, camera plate (optional, +11.7 g). Added: 2 jaws + rail (4.4 h) and the 4 base holes. The J3 interface (46 x 46 flange, 4 x M3 on 36 x 36, arm-side plane zeta 62.5) is unchanged, so the Wrist track can swap in the metal J3 kit without touching the hand.

## 3. Grip servo: registers, positions (ticks), closing-distance policy

Pinion r_p = 12 mm, 4096 ticks/rev -> 54.3249 ticks per mm of rack travel s; clamp per jaw = 0.85 T / (2 r_p); register = round(1000 T / 2.942) (VERIFY address / scale in test B2). "ticks" = relative to the mechanical zero s = 0; add 2048 for a servo zeroed at mid-range.

| TQ_limit_Nm | register_0_1000 | clamp_per_jaw_N | pct_of_stall | pct_of_rated_0p981 | note |
|---|---|---|---|---|---|
| 0.350 | 119 | 12.4 | 11.9 | 35.7 | positioning / pre-contact |
| 0.500 | 170 | 17.7 | 17.0 | 51.0 | light |
| 0.700 | 238 | 24.8 | 23.8 | 71.4 | RECOMMENDED TQ_CLAMP (spec 0.70 = about 25 N per jaw) |
| 0.850 | 289 | 30.1 | 28.9 | 86.6 |  |
| 1.000 | 340 | 35.4 | 34.0 | 101.9 | transport torque for >= 1 L (jaw across-layer SF 2.08 at the 1.0 mm voxel FE [2.65 at 1.5 mm], rack tab SF 2.08) |
| 1.177 | 400 | 41.7 | 40.0 | 120.0 | S1 firmware cap (1.2 x rated, 41.7 N): highest value ever commanded; also EEPROM Max_Torque_Limit = 400; jaw across-layer SF 1.77 at the 1.0 mm voxel FE (< 2: not for sustained holds) |
| 2.942 | 1000 | 104.2 | 100.0 | 299.9 | stall: never (single event only: jaw SF 1.3-1.9 vs single-event allowables, 1.0 / 1.5 mm voxel FE; S1 pinion tip-loading FAIL 0.89) |

Recommended: TQ_CLAMP = 0.70 N m (register 238, 24.8 N per jaw); TRANSPORT for >= 1 L = 1.0 N m (340; jaw across-layer SF 2.08 at the 1.0 mm FE mesh, rack tab SF 2.08); never above 1.177 N m (400): set EEPROM Max_Torque_Limit = 400 so a software error cannot command stall.

| position | jaw_displacement_from_hard_stop_mm | rack_travel_s_mm | pinion_angle_deg | ticks_from_mech_zero | ticks_zero_at_2048 | lip_gap_mm | cap_wall_gap_mm | groove_gap_mm | note |
|---|---|---|---|---|---|---|---|---|---|
| real mechanical closed hard stop | 0.00 | -2.25 | -10.74 | -122.2 | 1925.8 | 26.50 | 29.00 | 34.00 | s = -2.25 (0.25 mm beyond the S1 CSV -2.0; boolean-verified). Never command beyond. |
| closed command target without bottle | 0.10 | -2.15 | -10.27 | -116.8 | 1931.2 | 26.70 | 29.20 | 34.20 | 0.1 mm short of the hard stop, torque limit TQ_CLAMP |
| OPEN = approach = drop-over (recommended) | 10.00 | 7.75 | 37.00 | 421.0 | 2469.0 | 46.50 | 49.00 | 54.00 | lip gap 46.5 / cap-wall gap 49.0 / groove gap 54.0 mm (>= 46 at both cap and lip level); outer width 66 mm |
| wide open (diagnostic) | 20.00 | 17.75 | 84.75 | 964.3 | 3012.3 | 66.50 | 69.00 | 74.00 | inside the 43.5 mm travel; outer width 86 mm |
| real mechanical open hard stop | 45.75 | 43.50 | 207.70 | 2363.1 | 4411.1 | 118.00 | 120.50 | 125.50 | s = +43.5 (0.25 mm beyond the S1 CSV 43.25; boolean-verified) |

Stall positions on a cap (jaw lateral compliance included; k = 42.2 N/mm for A and 34.2 N/mm for B, series 18.9 N/mm; flex = F x 0.0529 mm/N for the pair):

| tq_Nm | tq_register | cap_od_mm | rack_delta_each_mm | ticks_from_mech_zero | ticks_zero_at_2048 | clamp_force_at_cap_N | regime |
|---|---|---|---|---|---|---|---|
| 0.35 | 119 | 29.5 | 0.000 | -122.2 | 1925.8 | 9.4 | hard stop (spring-limited) |
| 0.35 | 119 | 30.0 | 0.172 | -112.9 | 1935.1 | 12.4 | servo-limited |
| 0.35 | 119 | 30.5 | 0.422 | -99.3 | 1948.7 | 12.4 | servo-limited |
| 0.35 | 119 | 31.0 | 0.672 | -85.7 | 1962.3 | 12.4 | servo-limited |
| 0.35 | 119 | 32.0 | 1.172 | -58.6 | 1989.4 | 12.4 | servo-limited |
| 0.35 | 119 | 32.5 | 1.422 | -45.0 | 2003.0 | 12.4 | servo-limited |
| 0.70 | 238 | 29.5 | 0.000 | -122.2 | 1925.8 | 9.4 | hard stop (spring-limited) |
| 0.70 | 238 | 30.0 | 0.000 | -122.2 | 1925.8 | 18.9 | hard stop (spring-limited) |
| 0.70 | 238 | 30.5 | 0.094 | -117.1 | 1930.9 | 24.8 | servo-limited |
| 0.70 | 238 | 31.0 | 0.344 | -103.6 | 1944.4 | 24.8 | servo-limited |
| 0.70 | 238 | 32.0 | 0.844 | -76.4 | 1971.6 | 24.8 | servo-limited |
| 0.70 | 238 | 32.5 | 1.094 | -62.8 | 1985.2 | 24.8 | servo-limited |
| 1.00 | 340 | 29.5 | 0.000 | -122.2 | 1925.8 | 9.4 | hard stop (spring-limited) |
| 1.00 | 340 | 30.0 | 0.000 | -122.2 | 1925.8 | 18.9 | hard stop (spring-limited) |
| 1.00 | 340 | 30.5 | 0.000 | -122.2 | 1925.8 | 28.3 | hard stop (spring-limited) |
| 1.00 | 340 | 31.0 | 0.063 | -118.8 | 1929.2 | 35.4 | servo-limited |
| 1.00 | 340 | 32.0 | 0.563 | -91.7 | 1956.3 | 35.4 | servo-limited |
| 1.00 | 340 | 32.5 | 0.813 | -78.1 | 1969.9 | 35.4 | servo-limited |

Closing-distance policy for the planner (answer to the "rejected_closing_distance" question): the physical window is the cap-OD box 29.5-32.0 plus measurement error, i.e. at TQ 0.70 accept any stall between the hard stop (-122.2; 1925.8 with the 2048 offset) and the 32.5 mm position (-62.8; 1985.2), plus a few ticks of read-out tolerance. Below OD 30.3 mm the rack is ON the hard stop and the reading cannot distinguish "small cap" from "empty jaws" (clamp force 9-19 N from the jaw spring): treat "stalled at the hard stop with a bottle present" as VALID closure, not as a rejection. OD_est = 29.0 + 2 x delta_rack + 0.0529 x F_servo (valid when delta_rack > 0.05 mm).

## 4. Geometry and interfaces fixed by this design

Parameters (s2hand_build.py): D_CAP_HS 29.0 (cap-wall gap at the hard stop), lip face |x| = 13.25 (gap 26.5), groove |x| = 17.0 (gap 34.0), GROOVE_H 5.5, LIP_T 3.0, jaw top z' = 17.0 (the cap top at z' = 18 stands 1 mm ABOVE the jaw top: jaw top is 1 mm below the cap top, as in the master spec), BACK_CLR 4.0 (back wall y = 83.0, cap rear clearance 5.75 mm at cap 30.5), bore axis L3 = 104.0 ahead of the J3 axis, 45 deg x 6 mm lead-ins on all three zones, lip ramp 45 deg starting 10 mm ahead of the bore axis (ends 3 mm later; it leaves the ring-seat chord +-6.2 mm at the worst corner and +-8.7 mm at the nominal ring untouched; only the extreme ring 34 / cap 29.5 chord of +-10.3 mm is trimmed by 0.3 mm), jaw bottom zeta -15.3, jaw top zeta +4.7, strap top +27.45, rail down to zeta -51.5 and x = +-76.3, outer width of the open jaws 66 mm (46 mm closed).

Open gaps (recommended open / approach / drop-over position, delta 10 mm per jaw): lip level 46.5 mm, cap-wall level 49.0 mm, groove level 54.0 mm (>= 46 mm at both cap and lip level; nothing of the hand above z' = 17 over the bore; the strap / carrier are 74 mm behind the bore axis). Closed hard stop: 26.5 / 29.0 / 34.0 mm.

Mass / COM in the hand frame (closed pose; open pose x shifts by -0.09 mm):

| jaw_type | pose | camera_plate | delta_mm | mass_g | com_x_mm | com_y_mm | com_zeta_mm | com_zprime_mm | moving_mass_g |
|---|---|---|---|---|---|---|---|---|---|
| C | hard stop | False | 0.0 | 398.4 | 2.72 | 10.78 | 12.86 | 25.16 | 99.1 |
| C | hard stop | True | 0.0 | 410.1 | 4.09 | 10.47 | 13.65 | 25.95 | 99.1 |
| C | open (lip gap 46.5) | False | 10.0 | 398.4 | 2.63 | 10.78 | 12.86 | 25.16 | 99.1 |
| C | open (lip gap 46.5) | True | 10.0 | 410.1 | 4.01 | 10.47 | 13.65 | 25.95 | 99.1 |
| F | hard stop | False | 0.0 | 396.9 | 2.73 | 10.34 | 12.91 | 25.21 | 97.6 |
| F | hard stop | True | 0.0 | 408.6 | 4.10 | 10.05 | 13.70 | 26.00 | 97.6 |
| F | open (lip gap 46.5) | False | 10.0 | 396.9 | 2.64 | 10.34 | 12.91 | 25.21 | 97.6 |
| F | open (lip gap 46.5) | True | 10.0 | 408.6 | 4.02 | 10.05 | 13.70 | 26.00 | 97.6 |

Part masses (S1-calibrated shell + infill print-mass model, rms 7 % on the S1 parts; servo 55 g from design_params.json; screws / inserts 28 g and horn 9 g ASSUMED): jaw A 37.1 g, jaw B 40.4 g (type C), 36.3 / 39.6 g (type F), rail 44.4 g. Per-part masses, COM and the rack / pinion travel conventions are in the frame manifest (s2hand_frame_manifest.json).

## 5. Verification (boolean = manifold3d on the exported meshes; every check has a positive control)

1. Hard stops: first rack-vs-base/carrier overlap at s = -2.25 mm (S1 CSV -2.0, 0.25 mm further) and s = +43.5 (CSV 43.25); controls: 7.77 mm3 at s = -2.60 and 22.9 mm3 at 43.75 (s2hand_stops.csv).
2. Rack roll about x (rack pitch play dy +-0.3, dz +-0.6): feasible (< 1 mm3) up to 0.045 rad (0.0015 mm3 at 0.035, 0.36 at 0.045), infeasible at 0.05 (1.13 mm3); control 5.25 mm3 at 0.06 -> a jaw rigidly on the rack would have a free tip pitch of +-2.7 mm (jaw A) to +-4.6 mm (B): this is why the guide rail takes the vertical load (s2hand_rack_roll_scan.csv).
3. v1 attachment found: finger (44.3 wide plate under the base) bolted by 4 M3 along y into the yoke strap leg; the strap (y 22.15-30.15) has a through window for the rack tab (+-0.2 mm) and a vertical M3 retention screw into the tab insert. The new jaws replace finger + yoke + pad with one printed part per side that uses the same window and screw (so the rack tab geometry is not touched).
4. Base end-face inserts: wall >= 2.7 mm all around (floor side 2.7 analytic / 2.76 numeric); controls: hole 2 mm lower breaks out (0 mm wall), at y = 20 breaks out, at z = -0.2 leaves 1.57 mm.
5. Bottle fit, type C, 129 cases (nominal + 128 parameter-box corners; cap OD 29.5-32, ring OD 32-34, ring t 1.5-3, neck OD 24.5-26.5, free neck 3-10, shoulder 35-45, body D 71 = steepest 600 mL; [s2hand_bottle_scan_flat_CF.csv](s2hand_bottle_scan_flat_CF.csv)): seated 129/129 (clamp delta 0.209-1.457 mm, ring seat width 1.293-3.541 mm, seat area 21.9-100.2 mm2, lip-neck clearance 0.209-2.457 mm, first contact always the cap); heading approach at w = 0.2 / 1.2 / 2.2 mm: 129/129/129; vertical drop-over: 129/129/129; closing at the window w = 0.2 / 1.2 / 2.2: 129/121/113; release lowering D = 1 / 2 / 3 mm: 129/121/73. The only failures are the corner cap 29.5 + neck 26.5 + free neck 3.0 + short shoulder (jaw lip bottom meets the shoulder cone) and, for D = 3, ring t 3.0 (ring + D > GROOVE_H) - quantified by the free-neck rule below. Nominal bottle (600 mL, cap 30.5, ring 33 x 2): clamp delta 0.708 mm, seat width 2.54 mm, seat area 60.6 mm2, lip-neck clearance 1.21 mm.
6. Assembled frame: 15 meshes x 2 jaw types x 4 poses (closed, delta 10, 20, open hard stop) -> max pairwise overlap 0.0 mm3 over 440 pair-poses; 6 positive controls detected (17.8 - 1693 mm3, including the pinion rotated the wrong way: 77.7 mm3) ([s2hand_frame_interference.csv](s2hand_frame_interference.csv)). LEAD's independent audit of 576 placement poses also found zero.
7. Slot gauges: 49 boolean cases, all as expected (nominal bottles pass the slide-in at w = 1.2 / 2.2 and lowering with 0.0 mm3; ring 34 x 3 and ring 32 x 1.5 pass; controls detected: cap +0.6 mm 26-27 mm3, ring too large 14 mm3, ring 6.0 thick 9-59 mm3, neck too large 28-44 mm3, short free neck with a D110 shoulder 8-47 mm3) ([s2hand_gauge_checks.csv](s2hand_gauge_checks.csv)).

Free-neck rule ([s2hand_lip_free_neck_rule.csv](s2hand_lip_free_neck_rule.csv), 216 corners, worst corner = 2 L shoulder D110 / 35 mm, neck 26.5, cap 29.5): release lowering D (jaws loosened +0.5 mm or open) needs free neck >= LIP_T + D - 1.0 mm; closing at height w above the seat needs free neck >= LIP_T + w - 0.575 mm.

| lip mm | release lowering D mm | min free neck, worst corner | min free neck, 600 mL D71/35 | min free neck, D71/45 | Sim rule LIP_T + D + 0.5 |
|---|---|---|---|---|---|
| 2.00 | 1.00 | 2.00 | 1.25 | 0.75 | 3.50 |
| 2.00 | 2.00 | 3.00 | 2.25 | 1.88 | 4.50 |
| 2.00 | 3.00 | 4.00 | 3.25 | 2.75 | 5.50 |
| 3.00 | 1.00 | 3.00 | 2.25 | 1.88 | 4.50 |
| 3.00 | 2.00 | 4.00 | 3.25 | 2.75 | 5.50 |
| 3.00 | 3.00 | 5.00 | 4.25 | 3.88 | 6.50 |
| 4.00 | 1.00 | 4.00 | 3.25 | 2.75 | 5.50 |
| 4.00 | 2.00 | 5.00 | 4.25 | 3.88 | 6.50 |
| 4.00 | 3.00 | 6.00 | 5.25 | 4.75 | 7.50 |
| 5.00 | 1.00 | 5.00 | 4.25 | 3.88 | 6.50 |
| 5.00 | 2.00 | 6.00 | 5.25 | 4.75 | 7.50 |
| 5.00 | 3.00 | 7.00 | 6.25 | 5.88 | 8.50 |

Baseline 3.0 mm jaws give an effective 2.0 mm lip drop for free neck >= 4.0 mm (worst corner) / 3.25 mm (600 mL); the 2.0 mm lip (_lip2 set) for >= 3.0 mm / 2.25 mm. Add 0.5 mm margin if needed. The Sim rule is 1.5 mm more conservative than the real shoulder-cone geometry.
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

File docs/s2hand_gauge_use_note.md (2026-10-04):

# Gate-0 slot gauges - use note

**Use note (one paragraph)**: each gauge is the two jaw slot profiles (lip, groove and cap-wall steps, back wall at y = 83, 45 deg lead-ins, lip ramp) cut from a 20 mm slab and joined by a 4 mm back bridge at the face spacing of one cap-OD position (jaw displacement 0.25 / 0.75 / 1.50 mm = cap 29.5 / 30.5 / 32.0 mm; the lip / cap-wall / groove face gaps are 27.0 / 29.5 / 34.5, 28.0 / 30.5 / 35.5 and 29.5 / 32.0 / 37.0 mm; the lip2 gauge is the 30.5 position with a 2.0 mm lip). The notches in the top edge of the bridge count 1 / 2 / 3 / 4 (cap 29.5 / 30.5 / 32.0 / 30.5-lip2); in use the notched edge is the TOP, the part is printed lying on its back. Hold the gauge level, slot opening toward the bottle, push it onto the neck from the front about 1-2 mm below the final height until the cap approaches the back wall, then lift until the ring underside rests on the lip. **Good**: the cap sits between the cap-wall faces touching (or with a hair of play) for the gauge whose OD matches it, and with about 0.25 mm per side of visible gap for a cap 0.5 mm smaller; the ring lies in the groove with air above and beside it (groove 5.5 mm high, 34.5-37 mm wide); the lip tip is under the ring and the ring rests on it; the bottle hangs from the lip; the cap top stands about 1 mm ABOVE the jaw top for the nominal 18 mm cap (master spec: the jaw top z' = 17 is 1 mm below the cap top; a cap shorter than 17 mm ends below the jaw top and is also fine). **Failures and their meaning**: the cap does not enter the faces -> cap OD is larger than this gauge, use the next gauge (boolean: +0.6 mm = 26-27 mm3 overlap); the ring does not enter the groove or stops on the lead-in -> ring OD above the groove gap minus 0.5 mm or ring thicker than 5.5 mm (14 mm3 / 9-59 mm3); the gauge cannot be lifted to the ring because the lip does not pass under it -> free neck too short for the 3.0 mm lip, use the lip2 gauge (needs free neck >= 3.0 mm at a release lowering of 2 mm, >= 1.6 mm just to close at 0.2 mm above the seat); the neck wedges against the lip faces -> neck OD larger than the lip face gap (27.0 / 28.0 / 29.5 mm). All 49 boolean cases (nominal pass, tolerance extremes pass, controls fail) are in the gauge checks CSV.

| part | cap_od_position_mm | jaw_displacement_mm | lip_mm | lip_face_gap_mm | cap_wall_gap_mm | groove_gap_mm | back_wall_y_mm | mass_g_15pct_infill | bbox_x | bbox_y | bbox_z | identification |
|---|---|---|---|---|---|---|---|---|---|---|---|---|
| s2hand_gauge_cap29p5 | 29.5 | 0.25 | 3.0 | 27.0 | 29.5 | 34.5 | 83.0 | 12.8 | 39.3 | 20.0 | 48.0 | 1 notch(es) in the top edge of the back bridge (CAP 29.5) |
| s2hand_gauge_cap30p5 | 30.5 | 0.75 | 3.0 | 28.0 | 30.5 | 35.5 | 83.0 | 12.9 | 40.3 | 20.0 | 48.0 | 2 notch(es) in the top edge of the back bridge (CAP 30.5) |
| s2hand_gauge_cap32p0 | 32.0 | 1.50 | 3.0 | 29.5 | 32.0 | 37.0 | 83.0 | 13.0 | 41.8 | 20.0 | 48.0 | 3 notch(es) in the top edge of the back bridge (CAP 32.0) |
| s2hand_gauge_cap30p5_lip2 | 30.5 | 0.75 | 2.0 | 28.0 | 30.5 | 35.5 | 83.0 | 12.1 | 40.3 | 19.0 | 48.0 | 4 notch(es) in the top edge of the back bridge (CAP 30.5 L2) |

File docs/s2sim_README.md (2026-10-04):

# ElRobot2 S2-RC2 PET collar-jaw mode - MuJoCo S2 validation (SIM track, Phase 2 on the final Hand geometry): README and summary

Every table is generated by `s2sim_make_summary.py` from the CSV files named in the caption (column names are CSV column names).  Rerun instructions: section 11, files: section 12.

## 0. Deviations, interpretation choices and what was NOT assessed (read first)

1. **G4 acceptance (>= 57/60 in every cell) is NOT met.**  Grip-attributable count: 4 of 24 cells reach 57/60 (C 500 mL L0 lane 1: 57; C 500 mL L1 lane 1: 57; C 500 mL L1 lane 5: 57; F 500 mL L1 lane 3: 57); strict count: 0 of 24.  Totals over the 6 cells of each hand/bottle (grip-attributable / strict, of 360): C 500 mL 338 / 259; C 600 mL 261 / 178; F 500 mL 319 / 251; F 600 mL 232 / 156.  Failures over all 1440 draws: collision 173, not_in_lane 101, tipped 10, off_lane_x 6.  The dominant mechanism is the lateral placement error at the lane mouth (bottle body strikes a divider nose when the error exceeds the lane slack (73 mm - D)/2; 600 mL bodies of D 64-71 mm leave 1-4.5 mm), plus, for type F only, the lip dragging the bottle back out during the retreat (`not_in_lane`).  Nothing was relaxed.  **With the lateral error of the spec box reduced to +-1.5 mm (vision-centred, G4c; along-heading +-4 mm, vertical +-1.5 mm unchanged)** the cells reaching 57/60 grip-attributable are C 500 mL 6/6 cells (358/360 draws, strict 273); C 600 mL 6/6 cells (358/360 draws, strict 245); F 500 mL 5/6 cells (345/360 draws, strict 261); F 600 mL 0/6 cells (306/360 draws, strict 206) (section 6.2).
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

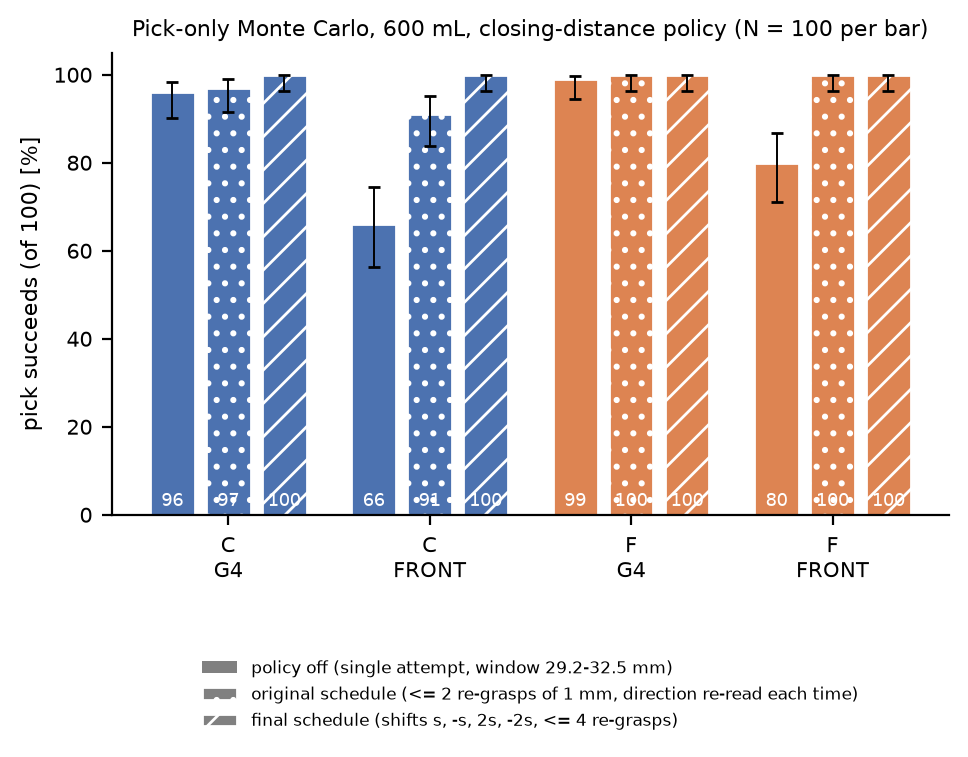
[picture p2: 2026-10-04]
img/s2sim_fig_pick_policy.png

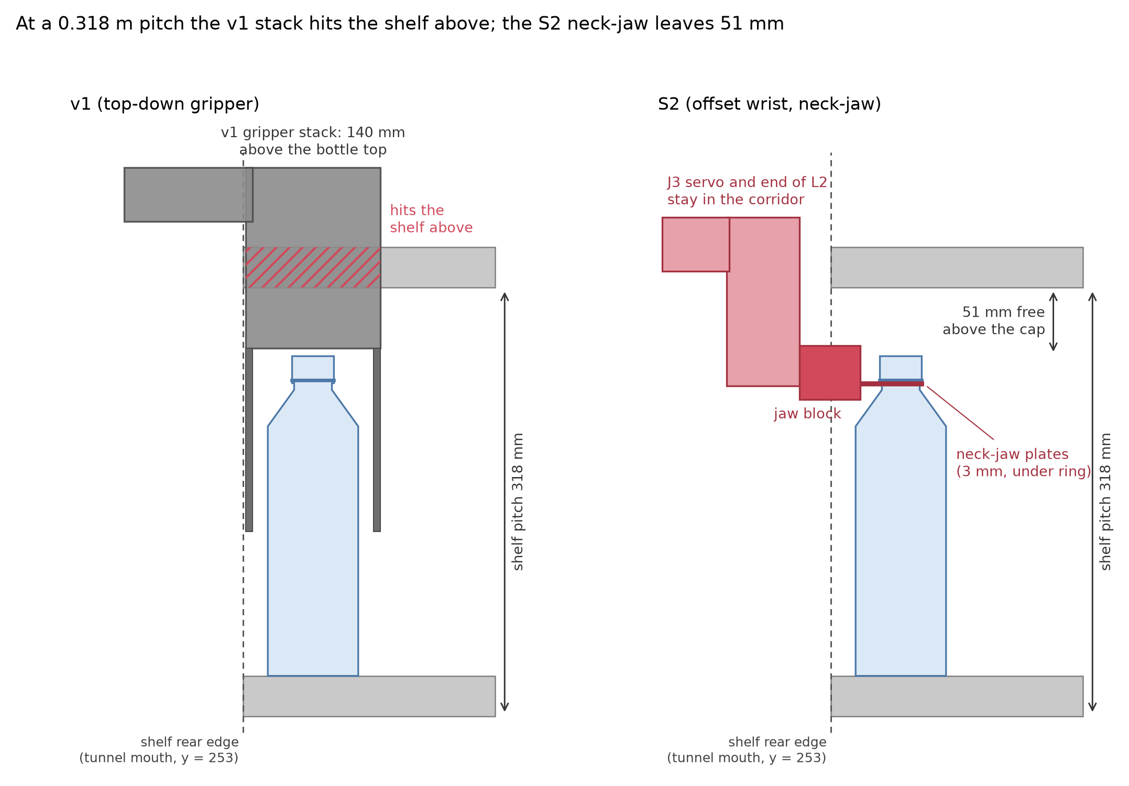
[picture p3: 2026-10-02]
img/fig_s2_vs_v1_side_view.png

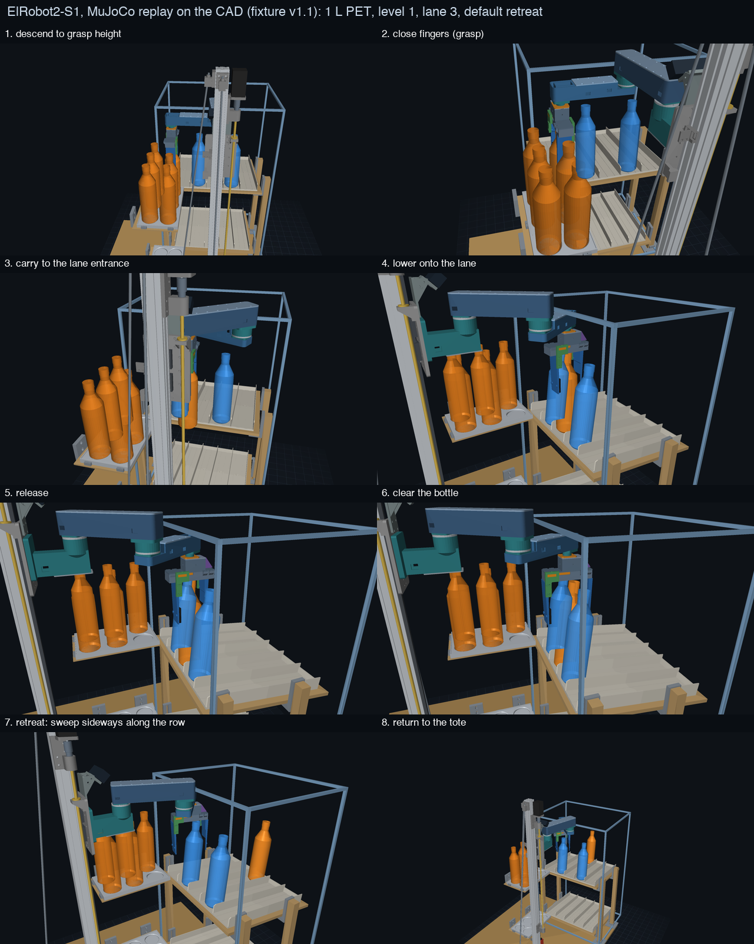
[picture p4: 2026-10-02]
img/ElRobot2_S1_replay_1L_keyframes_v11.png

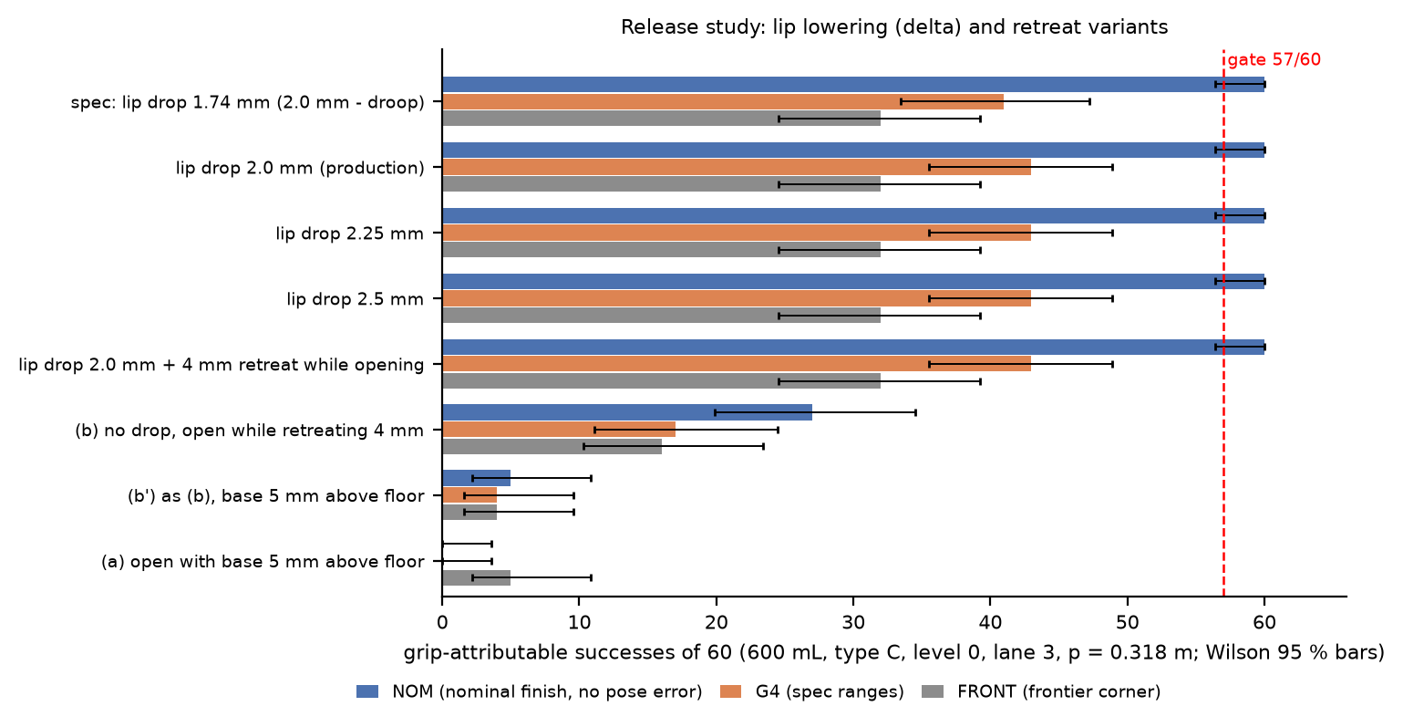
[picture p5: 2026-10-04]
img/s2sim_fig_release_variants.png

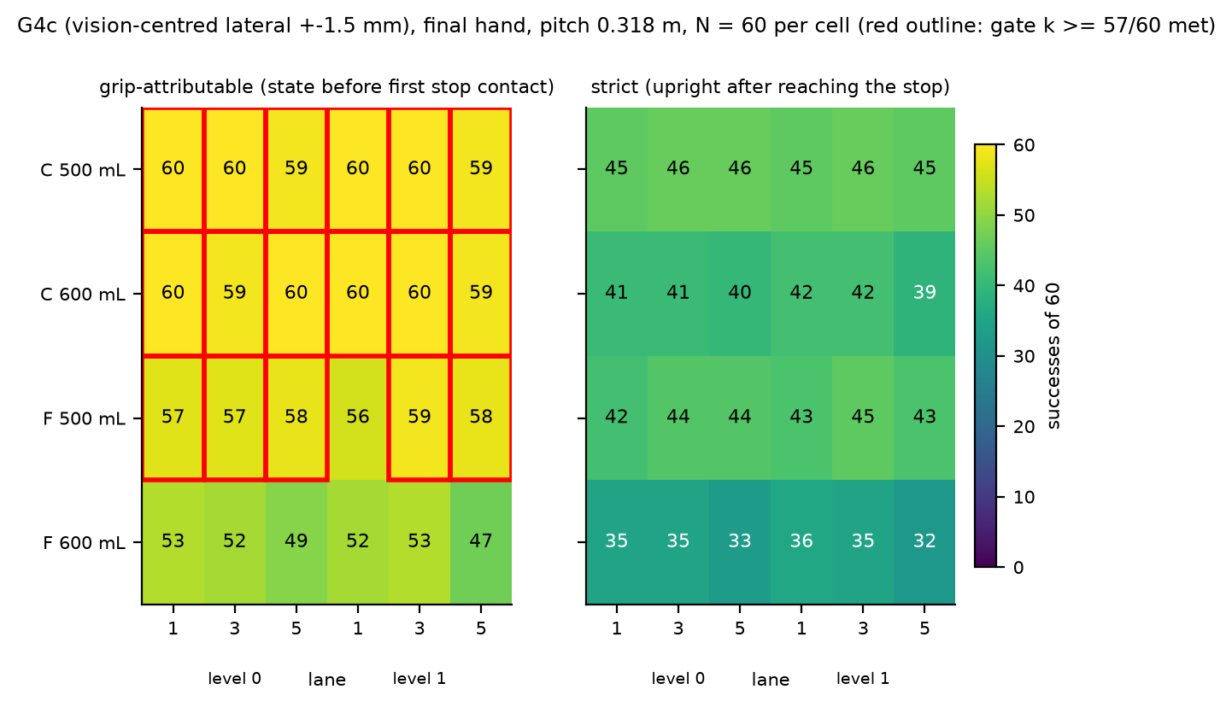
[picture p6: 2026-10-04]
img/s2sim_fig_g4_heatmap_g4c.png

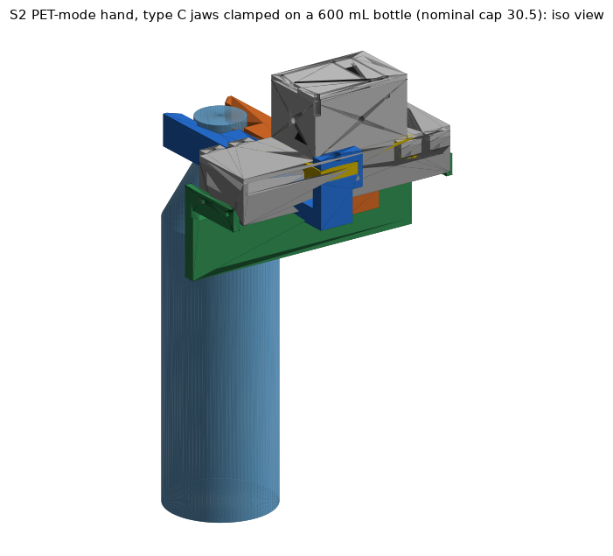
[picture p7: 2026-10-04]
img/s2hand_preview_iso_clamped.png

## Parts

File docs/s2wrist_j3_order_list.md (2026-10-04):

# S2 WRIST - J3 kit order list (generated by s2wrist_order_list.py)

Prices are NOT quotes (WEB = listing seen 2026-10-03, ESTIMATE = guess). Totals computed from s2wrist_j3_order_list.csv.

| lot | low USD | high USD |
|---|---|---|
| A: CNC kit parts + screws (A1-A4) | 103 | 250 |
| A: express shipping to Mexico (ESTIMATE, DHL / FedEx 3-7 days) | 35 | 70 |
| B: NO-CNC kit consumables + cutting + tools (B1-B7) | 85 | 266 |
| common: screws, cable, zip ties (C1-C6) | 12 | 30 |

## Paste block 1 - CNC quote request (option A)

Please quote 3 pcs of each of two small parts, aluminium 7075-T6 (6061-T6 as alternative), as-machined, edges broken 0.2-0.3, no anodising on the pin/hub/pegs. STEP files attached: s2wrist_j3_shaft_flange.step and s2wrist_j3_horn_plate_al.step. Critical dimensions (everything else ISO 2768-m):

- **J3 shaft-flange (CNC)** (qty 3): File s2wrist_j3_shaft_flange.step. Material 7075-T6 (6061-T6 acceptable fallback: payload limit 1.0 kg bottles, see README). Turn + mill. Overall 46 x 46 x 25 mm: flange 46 x 46 x 3.0 (+-0.1), R6 corners; hub D14.0 (+-0.1) x 1.6; pin D11.95 (+0.00/-0.02) from z 67.1 to 85.5, Ra <= 1.6 um; 2 pegs D3.0 (+0.00/-0.01) x 2.0 at (+-4.0, 0) +-0.05 on the pin top; 4 x D3.4 (+0.1/0) through on a 36 x 36 square (+-0.05); central bore D3.4 through with a 90 deg countersink D6.4 on the flange underside (DIN 7991 M3 flat head flush); R1.0 at the hub/flange fillet. Flange underside flat 0.05, pin perpendicular to it 0.03, pin/hub coaxial 0.03. Break all edges 0.2-0.3. NO anodise / hard coat on the pin, hub or pegs (mask them) - bare, bead-blast or chromate conversion only. ISO 2768-m elsewhere.

- **J3 horn plate (CNC)** (qty 3): File s2wrist_j3_horn_plate_al.step. Material 7075-T6 (or 6061-T6). Disc D24.0 (+0/-0.1) x 3.5 (+-0.05). From the bottom face: 4 x 90 deg countersink D6.2 x 1.6 for DIN 7991 M3 flat head on a 10 x 10 square (+-0.05) with D3.4 through; 2 x D3.1 (+0.05/0) x 2.2 deep at (+-4.0, 0) +-0.05 (peg holes); central M3 x 0.5 threaded hole (tap drill D2.5 x 3.0 deep, thread 2.5 deep). Break edges 0.2. Same finish note as A1.

Inspection report requested for: pin D11.95 (+0/-0.02), flange underside flatness 0.05, pin perpendicularity 0.03, hole positions.

## Paste block 2 - metal supplier / hardware shop (option B)

- **steel rod D12 (cold-drawn, drillable)** (to order: 5): D12 mm round bar, UNHARDENED steel: AISI/SAE 1018 or 1045, 12L14, or silver steel (annealed). h9 or better (11.957-12.000 mm). NOT a hardened chrome linear shaft (cannot be drilled / tapped) and not A2 stainless (work hardens). Cut to 23.0 - t_plate mm (20.00 mm for a 3.00 mm plate; 19.83 mm for 1/8 in = 3.175 mm plate), both end faces faced square (<= 0.05 mm over D12), 0.3 x 45 deg chamfers, no burrs. Order 150 mm and cut 5-6 pieces (2 kits + spares).

- **aluminium plate 3 mm (flat parts)** (to order: 6): 6061-T6 (or 5052-H32) sheet/plate, 3.0 mm (1/8 in = 3.175 mm is fine): NOT 1100/3003 or unknown 'aluminium sheet'. Cut from the DXF files s2wrist_nc_flange_plate.dxf (46 x 46, R6, 4 x D3.4 on 36 x 36, 3 x D3.0 on r 3.5) and s2wrist_nc_horn_plate.dxf (D24, 4 x D3.4 on 10 x 10, 2 x D3.2 (dowel holes, +0.1/0) at +-4,0 (if the plate does not seat over both dowels, open them by hand with a D3.2 drill, never larger)), 1:1, laser / waterjet / CNC router, tolerance +-0.1. Countersink afterwards with a 90 deg bit: D5.0 on the underside of the 3 holes on r 3.5 of the flange plate (head flush), D6.2 on the underside of the 4 holes on 10 x 10 of the horn plate. Deburr.

- **screws M2.5 x 8 DIN 7991 (flat head, steel 8.8)** (to order: 20): M2.5 x 8 countersunk flat head, DIN 7991 / ISO 10642, steel 8.8 (zinc / black oxide). NOT A2-70, NOT brass. 3 per arm. Fit with Loctite 243 or similar medium threadlocker.

- **dowel pins D3 x 6 ISO 2338 (m6, hardened steel)** (to order: 10): ISO 2338 / DIN 7 dowel pin 3 m6 x 6, steel; 2 per arm (4 mm pressed into the rod, 2 mm in the horn plate)

- **retaining compound (Loctite 638 or 648)** (to order: 1): Loctite 638 (high strength, slip-fit retaining compound, gap fill 0.15-0.25 mm) 10 mL (or 50 mL); used on the rod/bearing bores, rod top face + dowels. Plus a small bottle of medium threadlocker (Loctite 243).

- **printed parts (own printer)** (to order: 1): s2wrist_nc_collar (PETG, 100 %, ring ID 12.2 / OD 14.6 x (4.6 - t_plate): 1.60 mm for a 3.00 mm plate) x 2 + spares; s2wrist_nc_jig (PETG, 6 walls, 100 %) x 1 (socket D12.2 x 14 + guide holes D2.2 on r 3.5 (tap drill) and D3.2 at +-4,0 (dowel holes))

- **workshop tools (if not owned)** (to order: 1): drill press or good hand drill + vise; drill bits D2.05, D2.9, D3.2, D3.4; hand reamer D3.0 H7; M2.5 x 0.45 hand tap set (taper + plug) + tap wrench; 90 deg countersink bit; deburring tool; digital calipers 0.02 mm

- **socket cap screws M3 x 12 (ISO 4762, steel 8.8+)** (to order: 12): M3 x 12 socket head cap screw, 4 per mode (hand->J3 flange in PET mode, bar->J3 flange in CAN mode; the same 4 move between modes); order 12

- **bar pad screws M3 x 14 DIN 7991 (flat head)** (to order: 8): M3 x 14 countersunk flat head DIN 7991 / ISO 10642, steel 8.8 or A2-70; 4 per CAN hand; 5 mm bar pad + 3 mm hand top plate + 6 mm into the carrier inserts (as the S1 flange screws)

- **heat-set inserts Ruthex M3 x 5 x 4 (bar J3 block)** (to order: 8): same insert as the S1 (hole D4.2 x 9.5 deep in the bar block; 4 per bar)

- **servo extension cable, 3-pin, >= 300 mm** (to order: 2): Feetech STS/SCS 3-pin servo extension cable (same connector as the STS3215 lead), 300 mm; for the CAN hand (the stock lead is 150 mm)

- **cable ties 2.5 x 100 mm** (to order: 10): 2.5 mm wide, 2 per bar

- **6701-2RS bearings 12 x 18 x 4 (chrome steel)** (to order: 4): 2 per J3; chrome steel (C0r 530 N, AST catalogue). Stainless W 61701-2RS1 has C0r 260 N: do NOT substitute

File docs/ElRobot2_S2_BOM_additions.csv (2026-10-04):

order_batch | module | item | spec | qty | unit | price_low_usd | price_high_usd | price_basis | stock_status | option | notes
1 (long lead, 1-2 weeks) | S2 wrist | J3 shaft-flange (CNC) | File s2wrist_j3_shaft_flange.step. Material 7075-T6 (6061-T6 acceptable fallback: payload limit 1.0 kg bottles, see README). Turn + mill. Overall 46 x 46 x 25 mm: flange 46 x 46 x 3.0 (+-0.1), R6 corners; hub D14.0 (+-0.1) x 1.6; pin D11.95 | 3 | pc | 75.0 | 180.0 | ESTIMATE (JLCCNC lists CNC turning/milling 'from USD 5', 3 business days build; a prototyp | to buy | J3 kit option A (CNC) | order 3 = 2 + 1 spare; send the STEP + this text
1 (long lead, 1-2 weeks) | S2 wrist | J3 horn plate (CNC) | File s2wrist_j3_horn_plate_al.step. Material 7075-T6 (or 6061-T6). Disc D24.0 (+0/-0.1) x 3.5 (+-0.05). From the bottom face: 4 x 90 deg countersink D6.2 x 1.6 for DIN 7991 M3 flat head on a 10 x 10 square (+-0.05) with D3.4 through; 2 x D3 | 3 | pc | 24.0 | 60.0 | ESTIMATE | to buy | J3 kit option A (CNC)
1 (long lead, 1-2 weeks) | S2 wrist | tie screw M3 x 25 DIN 7991 (flat head, steel 8.8 or A2-70) | M3 x 25 countersunk flat head, DIN 7991 / ISO 10642, hex socket 2, zinc or black oxide, from the flange underside through the pin bore into the horn plate (replaces the S1 M3 x 20) | 6 | pc | 2.0 | 5.0 | ESTIMATE | to buy | J3 kit option A (CNC)
1 (long lead, 1-2 weeks) | S2 wrist | horn screws M3 x 6 DIN 7991 (flat head) | M3 x 6 countersunk flat head DIN 7991, 4 per arm (replaces the S1 M3 x 5: 2.2 mm instead of 1.2 mm engagement in the POM horn) | 12 | pc | 2.0 | 5.0 | ESTIMATE | to buy | J3 kit option A (CNC) | same SKU for option B
1 (local, 1-3 days) | S2 wrist | steel rod D12 (cold-drawn, drillable) | D12 mm round bar, UNHARDENED steel: AISI/SAE 1018 or 1045, 12L14, or silver steel (annealed). h9 or better (11.957-12.000 mm). NOT a hardened chrome linear shaft (cannot be drilled / tapped) and not A2 stainless (work hardens). Cut to 23.0 | 5 | pc | 4.0 | 12.0 | ESTIMATE | to buy | J3 kit option B (no CNC) | facing square is the critical workmanship item: it sets the hand tilt
1 (local, 1-3 days) | S2 wrist | aluminium plate 3 mm (flat parts) | 6061-T6 (or 5052-H32) sheet/plate, 3.0 mm (1/8 in = 3.175 mm is fine): NOT 1100/3003 or unknown 'aluminium sheet'. Cut from the DXF files s2wrist_nc_flange_plate.dxf (46 x 46, R6, 4 x D3.4 on 36 x 36, 3 x D3.0 on r 3.5) and s2wrist_nc_horn_ | 6 | pc | 25.0 | 75.0 | WEB: 0.125 in 6061-T6 blanks listed at USD 10.84 (3 x 3 in) and 13.38 (4 x 4 in) at tcipre | to buy | J3 kit option B (no CNC) | 6 flange plates + 6 horn plates would be overkill: order 3 of each
1 (local, 1-3 days) | S2 wrist | screws M2.5 x 8 DIN 7991 (flat head, steel 8.8) | M2.5 x 8 countersunk flat head, DIN 7991 / ISO 10642, steel 8.8 (zinc / black oxide). NOT A2-70, NOT brass. 3 per arm. Fit with Loctite 243 or similar medium threadlocker. | 20 | pc | 3.0 | 8.0 | ESTIMATE | to buy | J3 kit option B (no CNC)
1 (local, 1-3 days) | S2 wrist | dowel pins D3 x 6 ISO 2338 (m6, hardened steel) | ISO 2338 / DIN 7 dowel pin 3 m6 x 6, steel; 2 per arm (4 mm pressed into the rod, 2 mm in the horn plate) | 10 | pc | 3.0 | 8.0 | ESTIMATE | to buy | J3 kit option B (no CNC)
1 (local, 1-3 days) | S2 wrist | retaining compound (Loctite 638 or 648) | Loctite 638 (high strength, slip-fit retaining compound, gap fill 0.15-0.25 mm) 10 mL (or 50 mL); used on the rod/bearing bores, rod top face + dowels. Plus a small bottle of medium threadlocker (Loctite 243). | 1 | bottle | 25.0 | 93.0 | WEB: 50 mL listed at USD 54.81 (emisupply), 67.19 (Zoro), 87.81 (MSC), 92.53 (aftfasteners | to buy | J3 kit option B (no CNC) | cure 24 h at room temperature, fixture 5 min
1 (local, 1-3 days) | S2 wrist | printed parts (own printer) | s2wrist_nc_collar (PETG, 100 %, ring ID 12.2 / OD 14.6 x (4.6 - t_plate): 1.60 mm for a 3.00 mm plate) x 2 + spares; s2wrist_nc_jig (PETG, 6 walls, 100 %) x 1 (socket D12.2 x 14 + guide holes D2.2 on r 3.5 (tap drill) and D3.2 at +-4,0 (dow | 1 | pc | 0.0 | 0.0 | own print (17.5 g + 8.7 g incl. spares ~ 0.5 h) | own stock | J3 kit option B (no CNC)
1 (local, 1-3 days) | S2 wrist | workshop tools (if not owned) | drill press or good hand drill + vise; drill bits D2.05, D2.9, D3.2, D3.4; hand reamer D3.0 H7; M2.5 x 0.45 hand tap set (taper + plug) + tap wrench; 90 deg countersink bit; deburring tool; digital calipers 0.02 mm | 1 | pc | 25.0 | 70.0 | ESTIMATE | to buy | J3 kit option B (no CNC) | only what is missing
2 (hardware store) | S2 wrist | socket cap screws M3 x 12 (ISO 4762, steel 8.8+) | M3 x 12 socket head cap screw, 4 per mode (hand->J3 flange in PET mode, bar->J3 flange in CAN mode; the same 4 move between modes); order 12 | 12 | pc | 2.0 | 6.0 | ESTIMATE | to buy | common to both options
2 (hardware store) | S2 wrist | bar pad screws M3 x 14 DIN 7991 (flat head) | M3 x 14 countersunk flat head DIN 7991 / ISO 10642, steel 8.8 or A2-70; 4 per CAN hand; 5 mm bar pad + 3 mm hand top plate + 6 mm into the carrier inserts (as the S1 flange screws) | 8 | pc | 2.0 | 6.0 | ESTIMATE | to buy | common to both options | M3 x 14 exists in the DIN 7991 range; M3 x 16 would bottom in the insert
2 (hardware store) | S2 wrist | heat-set inserts Ruthex M3 x 5 x 4 (bar J3 block) | same insert as the S1 (hole D4.2 x 9.5 deep in the bar block; 4 per bar) | 8 | pc | 0.0 | 0.0 | own stock (S1 BOM: 100 ordered) | own stock | common to both options
2 (hardware store) | S2 wrist | servo extension cable, 3-pin, >= 300 mm | Feetech STS/SCS 3-pin servo extension cable (same connector as the STS3215 lead), 300 mm; for the CAN hand (the stock lead is 150 mm) | 2 | pc | 6.0 | 14.0 | ESTIMATE | to buy | common to both options | check connector pitch against your servo lead before ordering
2 (hardware store) | S2 wrist | cable ties 2.5 x 100 mm | 2.5 mm wide, 2 per bar | 10 | pc | 2.0 | 4.0 | ESTIMATE | to buy | common to both options
2 (hardware store) | S2 wrist | 6701-2RS bearings 12 x 18 x 4 (chrome steel) | 2 per J3; chrome steel (C0r 530 N, AST catalogue). Stainless W 61701-2RS1 has C0r 260 N: do NOT substitute | 4 | pc | 0.0 | 0.0 | S1 BOM (own stock) | own stock (material NOT verified: chrome or stainless; see the next row) | common to both options | ask the seller for the material
2 (hardware store) | S2 wrist | chrome-steel 6701-2RS bearings 12x18x4 from a known brand | bearing steel (52100 / GCr15), NOT stainless; C0r 530 N | 4 | pc |  |  | not priced (low cost) | to buy if the 20 on order are stainless or unmarked | common to both options | needed for payload above 0.72 kg; stainless carries 260 N
2 (hardware store) | S2 hand | M3 x 10 socket cap screws (rail brackets) | ISO 4762, 8.8 | 8 | pc |  |  | not priced (low cost) | to buy | S2 hand | 4 per hand + spares
2 (hardware store) | S2 hand | M3 x 8 socket cap screws + 0.5 mm washers (jaw retention) | ISO 4762 8.8; washers 0.5 mm thick | 4 | pc |  |  | not priced (low cost) | reuse the v1 yoke screws | S2 hand | 2 per hand
2 (hardware store) | S2 hand | PTFE adhesive film tape 0.08-0.10 mm | width 10-20 mm | 1 | roll |  |  | not priced (low cost) | to buy | S2 hand | guide gaps must be <= 0.12 mm (feeler gauge)
2 (hardware store) | S2 hand | heat-set inserts Ruthex M3 x 5 x 4 (base end faces) | 4 per hand | 4 | pc |  |  | S1 BOM second pack | second pack of 100 in the S1 BOM | S2 hand | S1 needs 120-144 against 100 ordered
3 (instruments) | Test | digital calipers 0.01 mm |  | 1 | pc |  |  | not priced | check stock | instruments | neck measurement (Gate 0)
3 (instruments) | Test | force gauge or spring / luggage scale (50 N class) |  | 1 | pc |  |  | not priced | to buy | instruments | clamp and pull-out forces (H2, H3), register check (B2)
3 (instruments) | Test | feeler gauge set 0.05-0.5 mm |  | 1 | set |  |  | not priced | to buy | instruments | guide gaps (H2)
3 (instruments) | Test | dial indicator 0.01 mm with magnetic base |  | 1 | pc |  |  | not priced | to buy | instruments | droop and J3 hang test (H2, H5)
3 (instruments) | Test | 1.3 kg test mass with a 104 mm lever |  | 1 | pc |  |  | own build | make from a water bottle bag or weights | instruments | J3 proof hang (H5)
3 (spares) | Spares | Feetech STS3095 C002 12 V | same C-suffix as J1/J2 | 1 | pc |  |  | not priced | to buy (optional) | spares | first collision tests may stall a joint
3 (spares) | Spares | Feetech STS3215 C018 12 V | same C-suffix as J3 / gripper | 1 | pc |  |  | not priced | 3 on hand: J3, gripper, 1 spare | spares | buy 1 more only if a spare is used
1 (long lead) | System | 12 V DC power supply 10 A regulated, fused | in the S1 BOM | 1 | pc |  |  | already counted in the S1 BOM (about US$25 ESTIMATE) | to buy | system | STS3095 stall current 9.8 A at 12 V

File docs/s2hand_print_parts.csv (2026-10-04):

part | group | qty_per_hand | material | watertight | volume_mm3 | mass_g | print_hours | bbox_x | bbox_y | bbox_z | fits_bed | orientation | supports | gate0_first | note
s2hand_stick_A_C | gate0 clip stick | 1 | PETG | True | 21118.0 | 17.2 | 0.77 | 20.0 | 77.0 | 22.0 | True | outer face (|x| = 23) down, slot face up: lip/groove/cap-wall steps print as terraces (no supports); strap window opens sideways | none | True | hand-held test head: jaw cut at y = 50 (full collar head, 22 x 20 mm handle); 1 L + 1 R per type
s2hand_stick_B_C | gate0 clip stick | 1 | PETG | True | 21118.0 | 17.2 | 0.77 | 20.0 | 77.0 | 22.0 | True | outer face (|x| = 23) down, slot face up: lip/groove/cap-wall steps print as terraces (no supports); strap window opens sideways | none | True | hand-held test head: jaw cut at y = 50 (full collar head, 22 x 20 mm handle); 1 L + 1 R per type
s2hand_stick_A_F | gate0 clip stick | 1 | PETG | True | 19853.0 | 16.4 | 0.75 | 20.0 | 77.0 | 22.0 | True | outer face (|x| = 23) down, slot face up: lip/groove/cap-wall steps print as terraces (no supports); strap window opens sideways | none | True | hand-held test head: jaw cut at y = 50 (full collar head, 22 x 20 mm handle); 1 L + 1 R per type
s2hand_stick_B_F | gate0 clip stick | 1 | PETG | True | 19853.0 | 16.4 | 0.75 | 20.0 | 77.0 | 22.0 | True | outer face (|x| = 23) down, slot face up: lip/groove/cap-wall steps print as terraces (no supports); strap window opens sideways | none | True | hand-held test head: jaw cut at y = 50 (full collar head, 22 x 20 mm handle); 1 L + 1 R per type
s2hand_jaw_A_C | jaw (type C) | 1 | PETG | True | 47277.0 | 37.1 | 1.37 | 42.8 | 147.0 | 29.0 | True | outer face (|x| = 23) down, slot face up: lip/groove/cap-wall steps print as terraces (no supports); strap window opens sideways | none | False
s2hand_jaw_B_C | jaw (type C) | 1 | PETG | True | 51332.0 | 40.4 | 1.47 | 42.8 | 157.1 | 29.0 | True | outer face (|x| = 23) down, slot face up: lip/groove/cap-wall steps print as terraces (no supports); strap window opens sideways | none | False
s2hand_jaw_A_F | jaw (type F) | 1 | PETG | True | 46012.0 | 36.3 | 1.35 | 42.8 | 147.0 | 29.0 | True | outer face (|x| = 23) down, slot face up: lip/groove/cap-wall steps print as terraces (no supports); strap window opens sideways | none | False
s2hand_jaw_B_F | jaw (type F) | 1 | PETG | True | 50067.0 | 39.6 | 1.45 | 42.8 | 157.1 | 29.0 | True | outer face (|x| = 23) down, slot face up: lip/groove/cap-wall steps print as terraces (no supports); strap window opens sideways | none | False
s2hand_guide_rail | common | 1 | PETG | True | 47610.0 | 44.4 | 1.6 | 152.6 | 56.5 | 48.0 | True | front face (y = 30) down, U opening up; brackets grow as 4 mm walls | none | False | rail + 2 end brackets: bolted M3x10 to the 4 base end-face inserts
s2hand_base_v2 | common (option: reprint) | 1 | PETG | True | 80938.0 | 72.3 | 2.44 | 144.0 | 58.3 | 25.3 | True | floor down, channels up (as S1) | none | False | S1 base + 4 insert holes D4.2 x 5.5; reprint ONLY if the drill template is not used
s2hand_drill_template | common (option: drill) | 2 | PETG | True | 4103.0 | 5.2 | 0.41 | 14.8 | 36.0 | 16.0 | True | plate flat | none | True | drill template for the 4 end-face holes of an existing S1 base (D4.3 guides); 1 per end, ~20 min each
s2hand_pad_tpu | option (TPU 95A) | 2 | TPU 95A | True | 147.0 | 0.2 | 0.26 | 1.0 | 14.0 | 10.5 | True | flat, 1.0 mm thick | none | False | 1 mm strip 14 x ~10.5; glue (CA) into the pocket of the _pad jaws; 4 pcs incl. 2 spares
s2hand_jaw_A_C_pad | jaw (type C, pad pocket) | 1 | PETG | True | 47130.0 | 37.1 | 1.38 | 42.8 | 147.0 | 29.0 | True | outer face (|x| = 23) down, slot face up: lip/groove/cap-wall steps print as terraces (no supports); strap window opens sideways | none | False | type C with a 1.0 mm pad pocket on the cap-wall face (use with s2hand_pad_tpu); cap-OD box unchanged
s2hand_jaw_B_C_pad | jaw (type C, pad pocket) | 1 | PETG | True | 51185.0 | 40.4 | 1.47 | 42.8 | 157.1 | 29.0 | True | outer face (|x| = 23) down, slot face up: lip/groove/cap-wall steps print as terraces (no supports); strap window opens sideways | none | False | type C with a 1.0 mm pad pocket on the cap-wall face (use with s2hand_pad_tpu); cap-OD box unchanged
s2hand_ladder_LIP2p0_GH5p5_D29p0 | tolerance ladder | 1 | PETG | True | 15766.0 | 17.5 | 0.78 | 46.0 | 48.0 | 22.0 | True | two heads side by side, outer faces down | none | True | ladder LIP2.0_GH5.5_D29.0: LIP_T = 2.0 (others nominal {'lip_t': 3.0, 'groove_h': 5.5, 'd_cap_hs': 29.0}); try on real bottles; hard-stop cap-wall gap D_CAP_HS
s2hand_ladder_LIP3p0_GH5p5_D29p0 | tolerance ladder | 1 | PETG | True | 16716.0 | 18.2 | 0.8 | 48.0 | 48.0 | 22.0 | True | two heads side by side, outer faces down | none | True | ladder LIP3.0_GH5.5_D29.0: LIP_T = 3.0 (others nominal {'lip_t': 3.0, 'groove_h': 5.5, 'd_cap_hs': 29.0}); try on real bottles; hard-stop cap-wall gap D_CAP_HS
s2hand_ladder_LIP4p0_GH5p5_D29p0 | tolerance ladder | 1 | PETG | True | 17674.0 | 19.0 | 0.83 | 50.0 | 48.0 | 22.0 | True | two heads side by side, outer faces down | none | True | ladder LIP4.0_GH5.5_D29.0: LIP_T = 4.0 (others nominal {'lip_t': 3.0, 'groove_h': 5.5, 'd_cap_hs': 29.0}); try on real bottles; hard-stop cap-wall gap D_CAP_HS
s2hand_ladder_LIP5p0_GH5p5_D29p0 | tolerance ladder | 1 | PETG | True | 18640.0 | 19.8 | 0.85 | 52.0 | 48.0 | 22.0 | True | two heads side by side, outer faces down | none | True | ladder LIP5.0_GH5.5_D29.0: LIP_T = 5.0 (others nominal {'lip_t': 3.0, 'groove_h': 5.5, 'd_cap_hs': 29.0}); try on real bottles; hard-stop cap-wall gap D_CAP_HS
s2hand_ladder_LIP3p0_GH3p5_D29p0 | tolerance ladder | 1 | PETG | True | 17156.0 | 18.4 | 0.81 | 48.0 | 48.0 | 22.0 | True | two heads side by side, outer faces down | none | True | ladder LIP3.0_GH3.5_D29.0: GROOVE_H = 3.5 (others nominal {'lip_t': 3.0, 'groove_h': 5.5, 'd_cap_hs': 29.0}); try on real bottles; hard-stop cap-wall gap D_CAP_HS
s2hand_ladder_LIP3p0_GH4p5_D29p0 | tolerance ladder | 1 | PETG | True | 16936.0 | 18.3 | 0.81 | 48.0 | 48.0 | 22.0 | True | two heads side by side, outer faces down | none | True | ladder LIP3.0_GH4.5_D29.0: GROOVE_H = 4.5 (others nominal {'lip_t': 3.0, 'groove_h': 5.5, 'd_cap_hs': 29.0}); try on real bottles; hard-stop cap-wall gap D_CAP_HS
s2hand_ladder_LIP3p0_GH5p5_D28p0 | tolerance ladder | 1 | PETG | True | 16636.0 | 18.1 | 0.8 | 48.0 | 48.0 | 21.5 | True | two heads side by side, outer faces down | none | True | ladder LIP3.0_GH5.5_D28.0: D_CAP_HS = 28.0 (others nominal {'lip_t': 3.0, 'groove_h': 5.5, 'd_cap_hs': 29.0}); try on real bottles; hard-stop cap-wall gap D_CAP_HS
s2hand_ladder_LIP3p0_GH5p5_D30p0 | tolerance ladder | 1 | PETG | True | 16796.0 | 18.4 | 0.81 | 48.0 | 48.0 | 22.5 | True | two heads side by side, outer faces down | none | True | ladder LIP3.0_GH5.5_D30.0: D_CAP_HS = 30.0 (others nominal {'lip_t': 3.0, 'groove_h': 5.5, 'd_cap_hs': 29.0}); try on real bottles; hard-stop cap-wall gap D_CAP_HS

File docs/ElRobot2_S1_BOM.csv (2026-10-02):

order_batch | module | item | spec | qty | unit | unit_price_usd | price_status | stock_status | notes | line_usd | in_total
1 (long lead) | Z module | 4040 V-slot column | 40x40 mm V-slot, TWO slots per face at 20 mm pitch (= 2x2 of 2020; OpenBuilds / ZYLtech V-Groove type), anodised 6063, centre bore; NOT a one-slot-per-face indu | 1.0 | pc | 50.0 | ESTIMATE | to buy | I = 8.14e-8 m^4 nominal (makers list 7.5-9.9 cm4), 1.55 kg/m (1.35-1.77). Mounted at x = -30..10 so the rail line x=0 sits over the front slot. Lean at z_c 1060: 2.45 mm alone (fails with a 7.5 cm4 pr | 50.0 | True
1 (long lead) | Z module | MGN12H rail + 2 blocks | rail 12x8 mm, 25 mm hole pitch, M3x8 rail bolts; blocks 27x45.4, 20x20 M3 pattern, M3x3.5 thread | 1.0 | pc | 64.0 | FOUND | to buy | HIWIN genuine blocks ~USD 21-45 each (makerstore.cc 21.20, Zyltech 12.95 clone); price varies 30-90 USD; usable operating stroke by rail length at 60 mm block spacing: 800 mm: 667 mm, 850 mm: 717 mm, | 64.0 | True
1 (long lead) | Z module | Lead screw T8x4 + brass flange nut | Tr8x4: 8 mm OD, 2 mm pitch, 2-start, 4 mm lead; nut flange D22, 4 holes on 16 mm circle (same footprint as the T8x8 nut) | 1.0 | pc | 12.0 | ESTIMATE | to buy | order the 2-start (4 mm lead) nut with the screw; speed limited to 40 mm/s cruise; 836 mm needed (top end 12.5 mm in coupler, bottom end 5 mm below lower bearing); hold on detent + friction needs the | 12.0 | True
1 (long lead) | Z module | NEMA17 stepper with 24 V power-off brake | OMC 17HS19-2004D-B070: 42x42x79 mm, 2.0 A/phase, 0.52 N*m, R 1.30 ohm, L 2.0 mH, shaft D5x24 (D-cut 15), brake 24 V 3.7 W 0.7 N*m, ~0.55 kg (gross 0.63-0.64 kg | 1.0 | pc | 29.26 | FOUND | to buy | longest-lead item: order first. Motor cable 500 mm, brake cable 180 mm (extend). Rotor inertia, detent torque and torque curve are not on the page: assumed 100 g*cm2 incl. brake hub and 25 mN*m detent | 29.26 | True
1 (long lead) | Z module | 5-to-8 mm flexible coupler | D20 x L25, set-screw or clamp | 1.0 | pc | 1.15 | FOUND | to buy | VERIFY bore depth >= 12 mm each side (shaft 11.5 mm, screw 12.5 mm engaged); D-cut flat on the motor shaft is 15 mm long, put the clamp screw on it | 1.15 | True
1 (long lead) | Z module | 608-2RS bearing | 8x22x7 | 4.0 | pc | 0.8800000000000001 | ESTIMATE | to buy | 2 per support (top + bottom). 6701/624 on order are not 608 | 3.52 | True
1 (long lead) | Z module | Shaft collar 8 mm | 8 mm bore, OD 14-16, set-screw, width ~10 | 2.0 | pc | 1.5 | ESTIMATE | to buy | 1 required (above top bearing), 1 spare; if OD > 12 add a 1 mm D12 shim so the collar bears on the inner race only | 3.0 | True
own print/stock | Z module | Printed spacer (PETG) | zmod_bearing_spacer: OD21 ID15 L18 | 2.0 | pc |  | own | own print | one per bearing pair | 0.0 | False
own print/stock | Z module | PETG filament for all printed Z-module parts | 13 distinct parts (spacer x2): plate 90.1 g, motor mount 52.0, bottom support 35.7, spacers 2x3.9, camera bracket 16.2, cradle 11.1, limit brackets 2x7.4, lower | 1.0 | pc |  | own | own print | orientations and supports per part in zmod_parts_table.csv; only the motor mount needs supports (under the upper arm); test the 22.1 mm bearing pockets with a fit coupon first | 0.0 | False
2 (hardware store) | Z module | M5x16 DIN912 + M5 slot T-nut (2020-series) | web, limit-bracket and rod-clamp screws into the 4040 slots | 16.0 | pc | 0.25 | ESTIMATE | to buy | 8 motor-mount + bottom-support webs (+x face), 4 limit brackets (-x face), 4 rod clamps (2 rear face, 2 -x face); 16 T-nuts (+2 spare) | 4.0 | True
2 (hardware store) | Z module | M5x25 DIN912 + M5 slot T-nut | lower stop (front slot) | 2.0 | pc | 0.3 | ESTIMATE | to buy | lower stop, front slot x=0 | 0.6 | True
2 (hardware store) | Z module | M3 slot T-nut (6 mm V-slot) | rail mounting, 25 mm pitch | 36.0 | pc | 0.1 | ESTIMATE | to buy | use every hole (36 on 900 mm) for rigidity; rail M3x8 bolts come with the rail | 3.6 | True
2 (hardware store) | Z module | M3x8 DIN912 | MGN12H block to carriage plate (8) + motor to mount (4) | 12.0 | pc | 0.05 | ESTIMATE | to buy | M3x10 on hand would bottom in the 3.5 mm block thread; use M3x8 | 0.6 | True
2 (hardware store) | Z module | M3x16 DIN912 + M3 nut + washer | nut flange to ledge | 4.0 | pc | 0.1 | ESTIMATE | to buy | nuts sit under the ledge, thread-lock | 0.4 | True
on hand / check | Z module | M3x10 DIN912 + M3 nut | camera bracket leg to plate (nut traps on rear face) | 4.0 | pc | 0.05 | ESTIMATE | on hand / ordered | tip ends flush with rear face; M3x12 gives margin | 0.2 | False
on hand / check | Z module | M2x12 DIN912 + M2 nut | limit switches to brackets (hex traps on rear) | 4.0 | pc | 0.05 | ESTIMATE | on hand / ordered | M2 nuts not on the order list | 0.2 | False
2 (hardware store) | Z module | M4x60 + M4 nyloc + washers | camera hinge and lock bolt | 2.0 | pc | 0.2 | ESTIMATE | to buy | lock bolt in arc slot; tighten for friction lock | 0.4 | True
2 (hardware store) | Z module | 1/4-20 UNC x 3/8 in bolt + washer | camera tripod thread | 1.0 | pc | 0.5 | ESTIMATE | to buy | pocket is 4.5 mm deep; head AF 11 | 0.5 | True
1 (long lead) | Z module | KW12-3 micro limit switch | 20x10x6.3 mm roller lever, 2 holes ~9.5 mm pitch D2.4 (VERIFY) | 2.0 | pc | 0.7 | ESTIMATE | to buy | home (bottom) + top; trip 3 mm beyond working range; wire NORMALLY CLOSED (COM + NC) so a broken wire reads as a trip; hole pitch / lever VERIFY on the received part | 1.4 | True
2 (hardware store) | Z module | Rubber bumper D20x10 | cylindrical, Shore ~60A | 2.0 | pc | 1.5 | ESTIMATE | to buy | 1 + spare; seat pocket D20.2 x 4 deep | 3.0 | True
on hand / check | Z module | Orbbec Gemini 2 | 90x25x30 mm, 1/4-20 bottom hole | 1.0 | pc |  | not | check | mass ~0.1 kg | 0.0 | False
2 (hardware store) | Z module | M6 threaded rod (tie rods) | M6 DIN 975 steel (zinc or A2), 2 m length, A_s 20.1 mm2, ~0.22 kg/m | 2.0 | pc | 4.0 | ESTIMATE | to buy | two separate 2 m pieces (a 1 m rod plus coupling nut would add a slack joint). Horizontal-equivalent rod stiffness 0.061 (rear) / 0.036 (side) N/um before the joints. Snug (not tensioned) at assembly | 8.0 | True
2 (hardware store) | Z module | M6 nut DIN 934 + M6 washer DIN 125 | rod ends: top nut + washer on the clamp seat; bottom nut captive in the anchor slot (AF 10, 5 mm) | 8.0 | pc | 0.1 | ESTIMATE | to buy | 4 nuts + 4 washers used, 4 spare of each; use a drop of thread-lock on the top nuts | 0.8 | True
2 (hardware store) | Z module | M5x60 DIN912 + M5 nyloc nut + M5 penny washer (anchor bolts) | rod anchor blocks to the plywood: 2 bolts per anchor, bolt head in the D10 counterbore, nut + 20 mm washer under the plywood | 4.0 | pc | 0.4 | ESTIMATE | to buy | bolt tension 143 N each at the design load (hand calc ROD2); drill D5.5 holes in the plywood at the positions in zmod_build.py ANCHOR_BOLTS (the CAD plywood has them) | 1.6 | True
2 (hardware store) | Z module | Plywood base 400 x 400 x 18 mm | birch / construction plywood, one piece; x -200..200, y -401..-1 (front edge 130 mm ahead of the column front face) | 1.0 | pc | 12.0 | ESTIMATE | to buy | mass 1.87 kg (650 kg/m3 ESTIMATE); column and ballast are not glued to it: bolt the 4 foot brackets, ballast plates on the rear half | 12.0 | True
2 (hardware store) | Z module | Column foot brackets (4) | 3 mm steel (or aluminium) angle bracket 40 mm wide, legs >= 36 mm (on the column slot) and >= 30 mm (on the plywood); one per column face | 4.0 | pc | 1.5 | ESTIMATE | to buy | M5x10 + T-nut on the column leg, 2x M5x30 + nut + washer through the plywood leg per bracket (8 bolts total); with the rods the base moment is <= 3 N*m (C-RODS), without them 18.8 N*m | 6.0 | True
2 (hardware store) | Z module | M5x30 DIN912 + M5 nut + washer (foot brackets) | bracket horizontal legs through the 18 mm plywood | 8.0 | pc | 0.2 | ESTIMATE | to buy | nan | 1.6 | True
2 (hardware store) | Z module | Ballast | steel plates / weights, 6 kg on the rear half of the plywood (lever >= 0.33 m); 11 kg if centred | 1.0 | pc | 15.0 | ESTIMATE | to buy | O1 static SF 2: 4.3 kg (rear) / 7.1 kg (centre); O3 dynamic SF 1.5 (2 m/s^2 at 1 m) governs: 6.5 / 10.8 kg; not modelled in CAD; the 400 mm base replaces the 300 mm one (ballast 14.2 kg -> 7.1 kg) | 15.0 | True
1 (long lead) | Z module | 24 V DC power supply 5 A | Mean Well EDR-120-24: 24 V 5 A 120 W DIN-rail, 100-240 VAC in (adjustable ~24-28 V: set 24.0 V, never above 25 V for the TMC2209) | 1.0 | pc | 29.89 | FOUND | to buy | feeds motor driver and brake only; arm servos stay on their 12 V supply; mains wiring only by a competent person / enclosed unit | 29.89 | True
2 (hardware store) | Z module | Fuse T3.15A slow-blow + holder | 5x20 mm slow-blow in the 24 V line after the supply | 1.0 | pc | 3.0 | ESTIMATE | to buy | sized above the ~1 A running current and the capacitor inrush, below what 1.0 mm2 wire and the driver tolerate (UNVERIFIED) | 3.0 | True
1 (long lead) | Z module | Stepper driver TMC2209 module (UART) | BigTreeTech TMC2209 V1.3 or Watterott SilentStepStick TMC2209 (0.11 ohm sense, VM 4.75-28 V); heatsink; spare 1 | 2.0 | pc | 8.0 | ESTIMATE | to buy | set 1.4 A rms (ASSUMED, UNVERIFIED): UART IRUN = 24 (1.38 A rms) or 25 (1.44 A rms) with vsense = 0 and R_sense 0.11 ohm, formula I_rms = (CS+1)/32 x 0.325 V/(R_sense + 0.02 ohm)/sqrt2; or analog Vref | 16.0 | True
2 (hardware store) | Z module | Brake switch: N-MOSFET + flyback diode (or 24 V relay) | logic-level N-MOSFET (IRLZ44N or similar) low side, 1N5819 / 1N4007 flyback diode across the brake coil, 100 ohm gate resistor, 10 kohm gate pull-down; relay al | 1.0 | pc | 2.0 | ESTIMATE | to buy | brake coil 3.7 W = 154 mA at 24 V; diode must be rated >= 1 A / 40 V | 2.0 | True
2 (hardware store) | Z module | E-stop: mushroom button NC + 24 V relay | 22 mm mushroom, latching, NC contact; DC power relay with 24 V coil, contacts >= 5 A DC at 24 V (switches 24 V to driver VM and brake) | 1.0 | pc | 12.0 | ESTIMATE | to buy | E-stop NC contact only carries the relay coil current; releasing it drops the relay -> motor power and brake power both cut -> brake engages; 12 V arm servo supply stays alive (see zmod_electrical.md) | 12.0 | True
2 (hardware store) | Z module | Bulk capacitor 470 uF 35 V + 100 nF ceramic | at the driver VM pins (< 20 mm leads) | 1.0 | pc | 0.6 | ESTIMATE | to buy | do not use a 25 V part: VM runs at 24 V with regeneration spikes (TMC2209 limit 28-29 V) | 0.6 | True
2 (hardware store) | Z module | Wire 1.0 mm2 + ferrules + terminal blocks | 2 colours (24 V +/-), motor and brake extensions, 4-pin / 2-pin connectors, NC switch wire 0.25 mm2 | 1.0 | pc | 10.0 | ESTIMATE | to buy | nan | 10.0 | True
1 (long lead) | Z module | Step/dir controller (optional if the arm controller supplies it) | Raspberry Pi Pico (RP2040) or ESP32 board: STEP, DIR, EN, UART TX/RX, HOME, TOP, BRAKE, ESTOP_OK pins (list in zmod_electrical.md) | 1.0 | pc | 5.0 | ESTIMATE | to buy | 3.3 V logic fits the TMC2209 VIO | 5.0 | True
on hand / check | Gripper | Feetech STS3215 C018 12 V (gripper drive) | tower pocket, shaft down | 1.0 | pc |  | own stock | on hand (3 loose) |  | 0.0 | False
2 (hardware store) | Gripper | 624-2RS bearing 4x13x5 | pinion journal | 1.0 | pc | 0.0 | own stock | on order (x10) |  | 0.0 | False
1 (long lead) | Gripper | M3 x 18 socket cap screw | pinion to horn, heads in the flange counterbores | 4.0 | pc | 0.05 | ESTIMATE | to buy |  | 0.2 | True
2 (hardware store) | Gripper | M3 x 12 socket cap screw | J3 hub to tower inserts (shared with the arm list) | 4.0 | pc | 0.05 | ESTIMATE | to buy | buy 8 (spares) | 0.2 | True
2 (hardware store) | Gripper | M3 x 8 socket cap screw | yoke to rack tab insert | 2.0 | pc | 0.05 | ESTIMATE | to buy |  | 0.1 | True
2 (hardware store) | Gripper | M3 x 16 socket cap screw | camera wedge | 2.0 | pc | 0.05 | ESTIMATE | to buy |  | 0.1 | True
on hand / check | Gripper | M3 x 10 socket cap screw | carrier/top plate/servo adjust/yokes/pads | 22.0 | pc | 0.0 | own stock | on hand (x300 ordered) | +12 for the four dummies | 0.0 | False
on hand / check | Gripper | M2 x 12 screw + M2 nut | camera board | 4.0 | pc | 0.05 | ESTIMATE | screws on hand; M2 nuts to buy |  | 0.2 | True
on hand / check | Gripper | Ruthex M3 x 5 x 4 heat-set insert | base 4, carrier 12, racks 2, fingers 12 | 30.0 | pc | 0.0 | own stock | on order (x100) | +12 for the dummies | 0.0 | False
on hand / check | Gripper | TPU 95A filament | pads | 1.0 | pc |  | own stock | on order | 21 g | 0.0 | False
2 (hardware store) | Arm | screw: M3x50 socket cap (DIN 912) - horn clamp screws | M3x50 socket cap (DIN 912) - horn clamp screws | 16.0 | pc | 0.12 | ESTIMATE | to buy | goes through floor/plate 6 + flange 5 + collar 5 + tube 27 + ring (J1 7 / J2 4 mm) into the horn; thread engagement 3.0 mm of the 3.5 mm horn (VERIFY horn thick | 1.92 | True
2 (hardware store) | Arm | washer: M3 Belleville/disc spring washer DIN 6796 (3.2x7x0.4) | M3 Belleville/disc spring washer DIN 6796 (3.2x7x0.4) | 16.0 | pc | 0.1 | ESTIMATE | to buy | keeps clamp preload as PETG creeps; tighten ~0.3 N*m | 1.6 | True
2 (hardware store) | Arm | screw: M3x16 socket cap | M3x16 socket cap | 6.0 | pc | 0.06 | ESTIMATE | to buy | screws enter from behind the plate | 0.36 | True
on hand / check | Arm | screw: M3x10 socket cap | M3x10 socket cap | 16.0 | pc | 0.0 | own stock | on hand / ordered | cap: 1.2 mm cap + 5 mm insert + 3.8 mm into relief; J3 housing: 3.8 mm floor + 5 mm insert | 0.0 | False
2 (hardware store) | Arm | screw: M3x8 socket cap | M3x8 socket cap | 4.0 | pc | 0.06 | ESTIMATE | to buy | 1.8 mm floor + 5 mm insert + 1.2 mm into relief | 0.24 | True
2 (hardware store) | Arm | screw: M3x10 flat/countersunk head (DIN 7991) | M3x10 flat/countersunk head (DIN 7991) | 22.0 | pc | 0.0 | ESTIMATE | to buy | countersinks 90 deg in 3 mm covers (head 1.7 mm) | 0.0 | True
2 (hardware store) | Arm | screw: M3x20 flat/countersunk head (DIN 7991) | M3x20 flat/countersunk head (DIN 7991) | 1.0 | pc | 0.06 | ESTIMATE | to buy | seat z64.1, tip z84.1; thread-forming into the D2.6 pilot (3.6 mm engagement); pin top key + D6 centring post engage first | 0.06 | True
2 (hardware store) | Arm | screw: M3x5 flat/countersunk head (DIN 7991) | M3x5 flat/countersunk head (DIN 7991) | 4.0 | pc | 0.06 | ESTIMATE | to buy | VERIFY horn thread depth; use M3x6 only if the horn is through-tapped | 0.24 | True
2 (hardware store) | Arm | screw: M3x12 socket cap | M3x12 socket cap | 4.0 | pc | 0.06 | ESTIMATE | to buy | gripper-side inserts supplied by the gripper track | 0.24 | True
on hand / check | Arm | insert: ruthex M3 heat-set 5x4 (hole D4.2, 9 mm deep incl. relief) | ruthex M3 heat-set 5x4 (hole D4.2, 9 mm deep incl. relief) | 50.0 | pc | 0.0 | own stock | on hand / ordered | J2 housing flange / J3 housing flange use 7.0 / 6.5 mm deep holes | 0.0 | False
1 (long lead) | Arm | bearing: 6806-2RS 30x42x7 | 6806-2RS 30x42x7 | 6.0 | pc | 4.5 | ESTIMATE | to buy | press-fit seat D42.1 (determine with coupon +0.0/+0.1/+0.2) | 27.0 | True
on hand / check | Arm | bearing: 6701-2RS 12x18x4 | 6701-2RS 12x18x4 | 2.0 | pc | 0.0 | own stock | on hand / ordered | seat D18.1 | 0.0 | False
on hand / check | Arm | servo: Feetech STS3095 (C002, 12 V) | Feetech STS3095 (C002, 12 V) | 2.0 | pc | 0.0 | own stock | on hand / ordered | VERIFY 30x65x48, shaft 17 mm from end, horn 3.5 mm / D30 | 0.0 | False
on hand / check | Arm | servo: Feetech STS3215 (C018, 12 V) | Feetech STS3215 (C018, 12 V) | 1.0 | pc | 0.0 | own stock | on hand / ordered | torque limit <= 1.0 N*m (pin shear) | 0.0 | False
on hand / check | Arm | filament: TPU 95A | TPU 95A | 1.0 | pc | 0.0 | own stock | on hand / ordered | nan | 0.0 | False
2 (hardware store) | Arm | misc: cable ties 2.5 mm | cable ties 2.5 mm | 1.0 | pc | 2.0 | ESTIMATE | to buy | nan | 2.0 | True
2 (hardware store) | Arm | screw: M3x8 button head ISO 7380 | M3x8 button head ISO 7380 | 2.0 | pc | 0.06 | ESTIMATE | to buy | plate 1.2 mm under head + 5 mm insert; tip 0.2 mm in relief | 0.12 | True
on hand / check | Arm | part: arm_j3_spacer (printed, OD17.9/ID15/10 mm) | arm_j3_spacer (printed, OD17.9/ID15/10 mm) | 1.0 | pc | 0.0 | own print | print | locates the upper bearing; upper bearing otherwise retained by press fit only | 0.0 | False
on hand / check | Fixture | Ruthex M3 x 5 x 4 brass heat-set insert | hole 4.2 x 5.5 deep, 220-230 C soldering iron | 40.0 | pc | 0.0 | own stock | on hand / ordered | STD lane segments: 2 per segment x 20 segments (10 entry + 10 exit) | 0.0 | False
2 (hardware store) | Fixture | M3 x 20 socket head cap screw | ISO 4762, steel | 40.0 | pc | 0.06 | ESTIMATE | to buy | lane segment to shelf plate, from below through the 12 mm plate into the insert | 2.4 | True
2 (hardware store) | Fixture | M3 washer | DIN 125, 7 mm OD | 40.0 | pc | 0.02 | ESTIMATE | to buy | under the plywood, one per M3 screw | 0.8 | True
on hand / check | Fixture | Ruthex M3 x 5 x 4 brass heat-set insert (WIDE set) | as above | 12.0 | pc | 0.0 | own stock | optional (on hand / ordered) | WIDE lanes: 3 lanes x 2 segments x 2 inserts (level 1 swap, OPTIONAL set) | 0.0 | False
on hand / check | Fixture | M3 x 20 socket head cap screw + M3 washer (WIDE set) | as above | 12.0 | pc | 0.06 | ESTIMATE | optional (to buy) | WIDE segments to the level-1 plate (OPTIONAL set) | 0.72 | False
2 (hardware store) | Fixture | M6 x 50 socket head cap screw | ISO 4762; head in the 11 x 6.5 counterbore of the bracket leg | 16.0 | pc | 0.25 | ESTIMATE | to buy | main bracket leg to post: 8 main brackets x 2 bolts (through the 12 mm leg + 30 mm wood post) | 4.0 | True
2 (hardware store) | Fixture | M6 hex nut + 2 x M6 washer (18 mm OD) | ISO 4032 / DIN 125 | 16.0 | pc | 0.3 | ESTIMATE | to buy | main bracket bolts (nut and washer on the far face of the post) | 4.8 | True
2 (hardware store) | Fixture | alt: M6 x 16 socket head cap screw + M6 T-nut | for 3030 T-slot posts | 16.0 | pc | 0.35 | ESTIMATE | alternative (excluded from totals) | same 16 main-bracket joints if 3030 aluminium posts are used instead of wood | 5.6 | False
2 (hardware store) | Fixture | M6 x 35 socket head cap screw | head in the 7 mm counterbore of the tote bracket leg | 8.0 | pc | 0.2 | ESTIMATE | to buy | tote bracket leg to the 18 mm plywood stand panel: 4 tote brackets x 2 bolts | 1.6 | True
2 (hardware store) | Fixture | M6 hex nut + 2 x M6 washer (18 mm OD) | as above | 8.0 | pc | 0.3 | ESTIMATE | to buy | tote bracket bolts (nut and washer on the outer face of the panel) | 2.4 | True
2 (hardware store) | Fixture | 4 x 30 countersunk wood screw | pilot 2.8 mm (fixture_plate_holes.csv) | 16.0 | pc | 0.04 | ESTIMATE | to buy | main bracket seat + wedge shim to the 12 mm shelf plate, from below: 2 per bracket x 8 | 0.64 | True
2 (hardware store) | Fixture | 4 x 20 countersunk wood screw | pilot 2.8 mm, 4 mm deep | 16.0 | pc | 0.04 | ESTIMATE | to buy | tote bracket seat (16 mm) to the 6 mm ledge plate: 4 per bracket x 4 | 0.64 | True
2 (hardware store) | Fixture | 3.5 x 16 wood screw | pilot 2.5 mm, 4 mm deep | 6.0 | pc | 0.03 | ESTIMATE | to buy | tote stops to the ledge plates (3 per ledge) | 0.18 | True
2 (hardware store) | Fixture | 5 x 25 wood / chipboard screw | countersunk or pan head | 16.0 | pc | 0.04 | ESTIMATE | to buy | post foot flange to baseboard: 4 per foot x 4 feet | 0.64 | True
2 (hardware store) | Fixture | 5 x 20 wood screw | nan | 12.0 | pc | 0.04 | ESTIMATE | to buy | post retaining screws through the foot socket walls: 3 per foot x 4 | 0.48 | True
2 (hardware store) | Fixture | 4 x 40 wood screw + wood glue | nan | 24.0 | pc | 0.05 | ESTIMATE | to buy | tote stand knee gussets: 6 screws per edge x 2 edges x 2 gussets | 1.2 | True
2 (hardware store) | Fixture | 4 x 50 wood screw + wood glue | from below through the base plate into the panel end grain | 6.0 | pc | 0.05 | ESTIMATE | to buy | tote stand panel to base plate | 0.3 | True
2 (hardware store) | Fixture | 5 x 30 wood screw | nan | 4.0 | pc | 0.05 | ESTIMATE | to buy | tote stand base plate to the baseboard (far corners) | 0.2 | True
1 (long lead) | Fixture | PTFE or UHMW-PE adhesive tape, 19 mm (3/4 in) wide, about 0.2 mm thick | thickness UNVERIFIED | 15.0 | pc | 1.6 | ESTIMATE | to buy | lane floors: 3 strips x 0.4 m x 10 lanes = 12.0 m net | 24.0 | True
1 (long lead) | Fixture | PTFE or UHMW-PE adhesive tape, 19 mm wide (WIDE set) | as above | 4.5 | pc | 1.6 | ESTIMATE | optional (to buy) | WIDE lanes: 3 strips x 0.4 m x 3 lanes = 3.6 m net (OPTIONAL set) | 7.2 | False
on hand / check | Fixture | Skate-wheel strips, 17 mm wide | dimensions UNVERIFIED | 30.0 | pc | 0.0 | ESTIMATE | optional (OPTIONAL) | OPTIONAL alternative lane floor (parts fixture_lane_entry_wheel / fixture_lane_exit_wheel, 3 channels per segment) | 0.0 | False
2 (hardware store) | Fixture | CA or 2-part epoxy | nan | 1.0 | pc | 8.0 | ESTIMATE | to buy | tote tray dovetail seams (2 STD trays + 1 D120 tray) | 8.0 | True
2 (hardware store) | Fixture | Birch plywood (or acrylic) 12 mm, 500 x 440 | cut list item 1-2 | 2.0 | pc | 9.0 | ESTIMATE | to buy | lane shelf plates, level 0 and level 1 | 18.0 | True
2 (hardware store) | Fixture | Birch plywood 6 mm, 205 x 315 | cut list item 3 | 2.0 | pc | 3.0 | ESTIMATE | to buy | tote ledge plates (extension beyond the brief) | 6.0 | True
2 (hardware store) | Fixture | Birch plywood 18 mm: panel 576 x 280, base plate 250 x 280, 2 gussets 200 x 200 | cut list items 6-8 | 1.0 | pc | 14.0 | ESTIMATE | to buy | tote stand (replaces the two tote posts) | 14.0 | True
2 (hardware store) | Fixture | Post 30 x 30 mm wood batten or 3030 aluminium, 599.6 mm | front posts x = +-278.0, y = 299.8 | 2.0 | pc | 6.0 | ESTIMATE | to buy | frame | 12.0 | True
2 (hardware store) | Fixture | Post 30 x 30 mm wood batten or 3030 aluminium, 573.4 mm | rear posts x = +-278.0, y = 548.5 | 2.0 | pc | 6.0 | ESTIMATE | to buy | frame | 12.0 | True
2 (hardware store) | Fixture | Common baseboard >= 18 mm plywood, 920 x 1000 mm (x -620..+300, y -420..+580), top face = world z 0 | x -620..+293, y -40..563 | 1.0 | pc | 25.0 | ESTIMATE | to buy (lead change: extended under the robot base) | common test bed; its top face is world z = 0 and must equal the robot base z = 0 | 25.0 | True
on hand / check | Fixture | Ruthex M3 inserts, M3 screws, 6806-2RS / 6701-2RS / 624-2RS bearings (coupon test fit only) | from the build stock | 4.0 | pc | 0.0 | own stock | on hand / ordered | fixture_coupon_bearing_seats.stl calibration: seats, insert holes, M3 clearance and counterbore holes, slide-fit slots | 0.0 | False
1 (long lead) | System | 12 V DC power supply 10 A (arm servo bus) | regulated, fused output; replaces the 5 A unit on hand | 1.0 | pc | 25.0 | ESTIMATE | to buy | STS3095 stall 9.8 A each; keep torque limits; fuse at the supply | 25.0 | True
2 (hardware store) | System | Inline blade fuse holder + 10 A fuse | 12 V rail | 1.0 | pc | 4.0 | ESTIMATE | to buy |  | 4.0 | True
2 (hardware store) | System | Power distribution block / terminal strip | 12 V and GND, 6 positions | 1.0 | pc | 6.0 | ESTIMATE | to buy | signal only through the Waveshare adapter | 6.0 | True
2 (hardware store) | System | Electrolytic capacitor 2200 uF 25 V | 12 V servo bus bulk | 1.0 | pc | 1.5 | ESTIMATE | to buy |  | 1.5 | True
on hand / check | System | Waveshare Bus Servo Adapter (A) | USB to servo bus | 1.0 | pc | 0.0 | own stock | on hand | VERIFY the adapter current rating before connecting two STS3095 | 0.0 | False
2 (hardware store) | System | USB cables / powered USB hub | adapter, Pico, cameras | 1.0 | pc | 15.0 | ESTIMATE | to buy |  | 15.0 | True
on hand / check | System | Orbbec Gemini 2, Logitech C922, Sonix wrist camera | perception | 1.0 | pc | 0.0 | own stock | on hand |  | 0.0 | False
1 (long lead) | System | Ruthex M3 x 5 x 4 heat-set inserts, second pack of 100 | need about 120 (144 with options) against 100 ordered | 100.0 | pc | 0.12 | ESTIMATE | to buy | insert count: gripper 30 (+12), arm 50, fixture 40 (+12) | 12.0 | True
2 (hardware store) | System | Assorted M3 socket cap screws 8/12/16/18/20/50 mm (kit) | see consolidated fastener table | 1.0 | pc | 15.0 | ESTIMATE | to buy | buy the sizes in ElRobot2_S1_BOM_fasteners.csv | 15.0 | True
on hand / check | System | ArUco markers 20-23, 80 mm | calibration | 4.0 | pc | 0.0 | own stock | on hand |  | 0.0 | False
on hand / check | System | Bambu Lab X2D, PETG (black, gray), TPU 95A | printing | 1.0 | pc | 0.0 | own stock | on hand | about 8-9 kg of PETG for everything incl. the fixture; stage the fixture | 0.0 | False

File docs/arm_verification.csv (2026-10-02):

id | category | check | value | criterion | status | note
V001 | datum_stack_level | j1_flange_top | 145.00 mm (nominal 145.00, dev +0.00) | |dev| <= 0.5 mm | PASS | hub zmax
V002 | datum_stack_level | j1_cap_top | 139.50 mm (nominal 139.50, dev +0.00) | |dev| <= 0.5 mm | PASS | cap zmax
V003 | datum_stack_level | j1_hsg_top | 135.10 mm (nominal 135.10, dev +0.00) | |dev| <= 0.5 mm | PASS | cap zmin (seat plane)
V004 | datum_stack_level | j1_horn_top | 101.00 mm (nominal 101.00, dev +0.00) | |dev| <= 0.5 mm | PASS | ring zmin (rests on horn)
V005 | datum_stack_level | j1_hub_len | 44.00 mm (nominal 44.00, dev -0.00) | |dev| <= 0.5 mm | PASS | hub zmax - ring zmin
V006 | datum_stack_level | j1_servo_bot | 49.50 mm (nominal 49.50, dev +0.00) | |dev| <= 0.5 mm | PASS | servo dummy zmin
V007 | datum_stack_level | l1_floor_bot | 145.00 mm (nominal 145.00, dev +0.00) | |dev| <= 0.5 mm | PASS | L1 zmin
V008 | datum_stack_level | j2_servo_top | 198.00 mm (nominal 198.00, dev +0.00) | |dev| <= 0.5 mm | PASS | L1 wall top (cover seat)
V009 | datum_stack_level | j2_clamp_top | 201.00 mm (nominal 201.00, dev +0.00) | |dev| <= 0.5 mm | PASS | L1 cover zmax
V010 | datum_stack_level | j2_horn_bot | 146.50 mm (nominal 146.50, dev +0.00) | |dev| <= 0.5 mm | PASS | J2 ring zmax (rests on horn)
V011 | datum_stack_level | j2_hsg_bot | 115.40 mm (nominal 115.40, dev +0.00) | |dev| <= 0.5 mm | PASS | J2 housing zmin
V012 | datum_stack_level | j2_cap_bot | 111.00 mm (nominal 111.00, dev +0.00) | |dev| <= 0.5 mm | PASS | J2 cap zmin
V013 | datum_stack_level | j2_hubfl_bot | 105.50 mm (nominal 105.50, dev +0.00) | |dev| <= 0.5 mm | PASS | J2 hub zmin
V014 | datum_stack_level | j2_hub_len | 36.00 mm (nominal 36.00, dev +0.00) | |dev| <= 0.5 mm | PASS | ring zmax - hub flange top
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

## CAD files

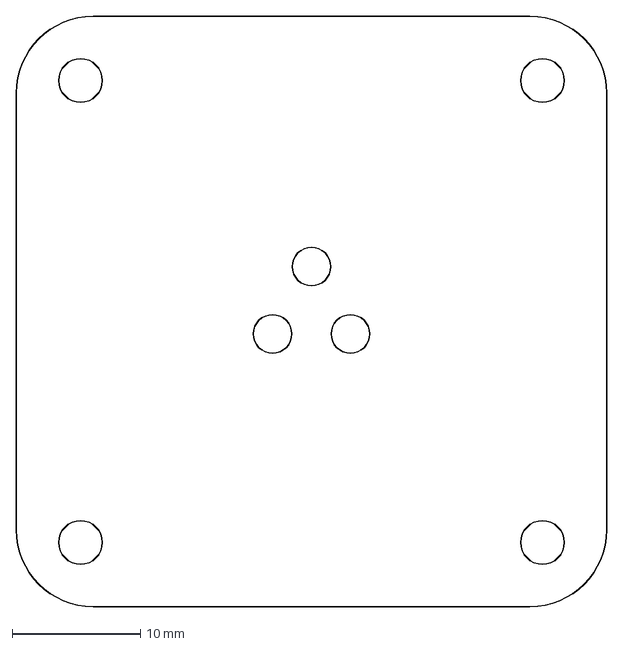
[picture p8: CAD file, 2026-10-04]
img/s2wrist_nc_flange_plate.dxf
46.0 x 46.0 mm

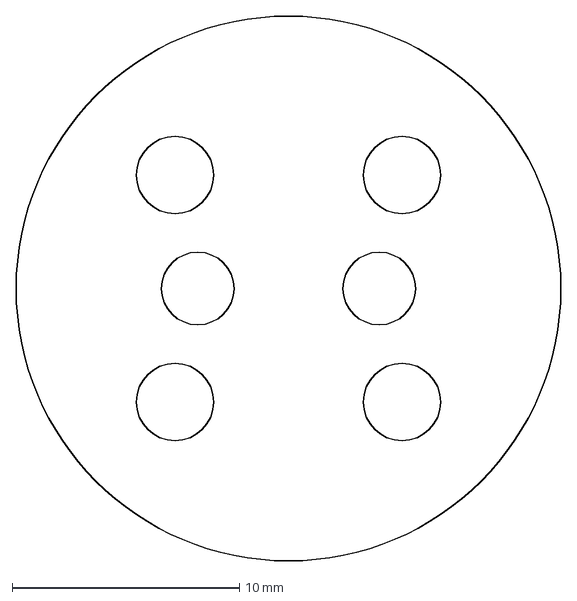
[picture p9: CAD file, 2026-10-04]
img/s2wrist_nc_horn_plate.dxf
24.0 x 24.0 mm

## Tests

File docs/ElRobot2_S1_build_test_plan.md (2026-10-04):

# ElRobot2 build sequence and test plan (v2.5, 2026-10-04: S1 body and S2-RC2 neck-grip hand)

Status: v2.3 (2026-10-02) changes the plan after the user removed glass and returnable containers from scope and stated that a store visit, a scale with real containers and a tilt-friction test are not available for now. (a) Glass and returnable containers are out of the plan (not deferred). (b) Phase S and tests A5-A7 become optional and non-blocking; the design runs on desk-research values (cooler_envelope_evidence.csv, design_params v0.4.3: shelf pitch 0.287-0.381 m with 0.318 m design-driving, lane 75 mm, wet pad friction 0.3 for printed TPU). (c) The v1 gripper stack stands 140 mm above the object and cannot serve a 600 mL or larger PET bottle in the standard racks found; Phases B and E therefore test the v1 gripper on fixture v1.1 (open racks, 0.44 m pitch) as a development tool only, and the new Phase H tests the S2 end effector (offset wrist, neck-jaw, flat clamp; S2_design_brief.md). Everything else equals v2.2 (which added Phase S, A7 and glass/returnable friction), v2.1 and the 2026-10-01 draft. It reflects the corrected clamp forces (34.7 N rated per finger), the Z module v0.6.1 (4040 column, tie rods, T8x4 screw, brake motor on 24 V, camera raised 38 mm), the arm and gripper as built in CAD (rev 4), fixture v1.1 (level pitch 0.44 m), the master assembly checks on the real CAD and the final MuJoCo rerun on fixture v1.1 (bay rule recommended; the wide-lane set is not). Numbers marked (sim) come from the MuJoCo model, (calc) from hand calculations, (FE) from the voxel finite-element checks, (CAD) from boolean checks on the real CAD meshes. Everything marked VERIFY is an assumption that a caliper, scale or bench test must confirm before it is trusted. Nothing in this project has been printed or built yet.

Status v2.4 (2026-10-04): Phase H is rewritten for the S2-RC2 neck-grip hand (collar jaws on the S1 gripper body), the metal J3 kit and the can-mode limits. New in this version: Gate 0 (H0 neck measurement and H1 printed slot gauges) before any jaw is printed; grip-servo registers and positions (238 / 340 / never above 400; closed hard stop 1925.8 ticks, open 2469.0); PTFE-shimmed guide gaps; the printed J3 chain may not carry a bottle; can-mode lane placement is NOT validated (retreat blocked). The S2-RC2 design report gives the verification behind each number (CAD booleans, exact-mesh placement audit, MuJoCo Monte Carlo). Nothing in this project has been built or tested on hardware yet.

## Safety rules for every session

1. Hands stay out of the arm envelope while any rail is powered. The Z E-stop (mushroom button, normally closed) cuts the 24 V rail (stepper, brake); the 12 V servo bus stays alive on purpose so the arm holds its pose. Press it once with an empty carriage before the first loaded run (the brake must lock, the arm must hold).
2. First motion of each session at 20 % speed and 40 % torque limit. Servo torque limits: gripper register 238 (0.70 N*m) for the S2 grasp, 340 (1.0 N*m) transport for 1 L, never above 400 (1.177 N*m; set the EEPROM Max_Torque_Limit to 400; VERIFY the register address and scaling in test B2); J3 register 200 (0.59 N*m) with the metal kit, 130 (0.38 N*m) with the printed chain; J1/J2 at most 40 % of their rated torque during the first runs.
3. Never test the Z column with a hand on the carriage. Never run it unattended until test C3 and the brake test have passed.
4. The column base (400 x 400 x 18 mm plywood) carries 6.5 kg (rear half) to 10.8 kg (centre) of ballast; bolt it to the common baseboard or clamp it to the table before the arm is extended.
5. Keep water away from the PSUs and terminals (wet bottles are part of the test plan). Fuse every rail (12 V rail at the supply, 24 V rail T3.15 A).

## Phase S (optional, not available now). Real cooler survey

| ID | Test | Procedure | Record | Pass |
|---|---|---|---|---|
| S1 | Survey of one real rear-loaded cooler (optional) | Fill in hoja_levantamiento_refrigerador_OXXO.pdf at one store if a visit becomes possible (shelf pitch A and clear gap B on three shelves, corridor F, access door G, glide lane width, photographs). Not required for any design step. | The filled sheet and the photographs | Replaces the desk-research pitch range 0.287-0.381 m with a measurement. The sheet's thresholds (430 / 410 / 310 mm) describe the v1 stack only; with S2 the thresholds are 287 mm (600 mL, neck-jaw), 322 mm (600 mL, flat clamp) and 208 mm (355 mL can, flat clamp). F at least 650 mm and G at least 450 mm wide: the robot fits. |

## Phase A. Coupons and measurements before the large prints (about 6 h of printing; A5-A7 optional)

| ID | Test | Procedure | Record | Pass |
|---|---|---|---|---|
| A1 | Servo pocket coupons (STS3215 gripper coupon, STS3095 arm coupon) | Print both coupons (arm_coupon_sts3095, gripper_coupon_sts3215). Seat a real servo in each. Measure body, shaft position from the horn-side face and the side wall, horn bolt pattern and spline depth with a caliper. | servo_dims.json, each value to 0.1 mm | Servo drops in by hand with no force and no rocking above 0.3 mm. Shaft offset within 0.5 mm of the model (STS3215 12.5 mm from the horn-side end, STS3095 17 mm). Otherwise edit the named parameter and rebuild (all parts are parametric). |
| A2 | Bearing seat coupons | fixture_coupon_bearing_seats (6806 / 6701 / 624) and a D22.1 ring for the 608. Seat diameters nominal +0.00 / +0.10 / +0.20 mm, production settings (6 walls, 0.2 mm layers). | Seat diameter per bearing | Light thumb pressure, spins freely, no perceptible radial play. The 6806 seat is the critical one (J1 and J2 carry the whole 12.2 N*m tilt moment). |
| A3 | Gear mesh coupon | Print the pinion (flange side down) and one rack at production settings. Turn the pinion by hand against the rack over the full 42.5 mm stroke. | Binding positions, backlash by dial indicator | Free over the whole stroke, backlash 0.1-0.4 mm. The CAD minimum flank gap is only 0.08 mm; printed gears usually need more. The servo pocket has +-2 mm adjusters to tune the centre distance; if it binds at the adjuster limit, thin the pinion teeth by 0.1 mm (named parameter). |
| A4 | Mass check | Weigh every printed part and assembly. | Mass table | Gripper 0.44 kg total, L1 side 0.627 kg, L2 side 0.303 kg, J1 turret 0.555 kg (Z-module estimate), carriage group 0.238 kg: each within 15 %. The printed gripper is 0.3355 kg against a 0.25 kg target (over budget, no lightening done). |
| A5 | Pad friction (optional, deferred) | Glue TPU pad stock to a flat board, tilt a clean dry PET bottle on it until it slips, repeat wet. Needs only a bottle and a board. | mu dry, mu wet | Dry at least 0.5 and wet at least 0.3. The v1 simulation assumes 0.8 dry and 0.4 wet; the desk-research design value for printed TPU 95A is 0.3 wet (an inference: published values are all dry, 0.2-1.0, on other surfaces; nothing found for wet PET at 4 C). Until A5 is done, PET at 1 L needs cast PU or silicone pads or the neck-jaw, and the clamp limits stay as designed (gripper_clamp_limits.csv, Figure 3, payload_mass_scenarios.csv). |
| A6 | Real SKU measurements (optional, deferred; cans and PET only) | Caliper D and H of any bottles and cans at hand (500 mL, 600 mL, 1 L, can) and, for S2, the PCO-1881 neck: support-ring outside diameter, ring thickness, free neck below the ring, cap top to ring underside. Weigh with any scale if available; density = (full - empty) / poured volume. Enter everything in container_data_sheet.csv. | bottle_sku_envelope.csv, container_data_sheet.csv | The 1 L diameter and base cup are estimates (D76-82; the simulation assumes a base cup 0.94 D that fits a D75 pocket only up to D 79.3 mm). The neck values replace the assumed ring OD 33 mm and the 4 mm free neck in the S2 brief (test H1). |
| A7 | Grip table from measured masses (optional, deferred) | Recompute payload_mass_scenarios.csv with measured masses and the A5 friction. | Updated payload_mass_scenarios.csv | Every friction-clamped SKU needs F = 2 m (g + 0.5 g) / (2 mu) at most 41.7 N per finger at the wet friction (about mu >= 0.353 m per kg); SKUs above that are rejected by the planner, not gripped harder. The 1 L is commanded at the cap when wet. |

## Phase B. Gripper bench (half a day; the v1 gripper is a development tool, see Phase H for PET in standard racks)

| ID | Test | Procedure | Pass |
|---|---|---|---|
| B1 | Gap calibration | Close on the calibration cylinders (D66, D71, D89, D105 dummies printed with the gripper) and on empty. Record servo ticks and caliper gap; fit a line (2309 ticks span 40-125 mm, 202.9 deg of pinion rotation). | Fit residual at most 1.0 mm over 40-125 mm; repeat closing to the same cylinder within 0.5 mm. |
| B2 | Clamp force and torque-limit register | Squeeze a luggage-scale or kitchen-scale force gauge at 20, 40, 60, 100 % of the commanded torque limit; find the register value that gives 34.7 N and 41.7 N. | Force at the rated setting within 20 % of 34.7 N per finger (calc); monotonic with the register; the 41.7 N cap (1.2 x rated) is the highest value ever commanded in normal use. Stall (104.2 N) is covered only by this cap: pinion tip-loading stall margin is 0.89 (FAIL) at b = 14 mm without it. |
| B3 | Hold test | 600 mL bottle at 25 N, can at 15 N, 1 L at 34 N (command limits); lift 0.2 m and shake horizontally at about 0.5 g 20 times; repeat wet. | At most 2 mm slip, no drop, 20 of 20 dry. Wet 1 L needs 39 N against the 34 N default limit (design_params v0.4.2 commands the wet 1 L at the 41.7 N cap, and the printed-pad design friction of 0.3 would need 53 N): record where it fails; the 1 L is a neck-jaw or cast-pad case. 1.5 L and 2 L are burst-only (47 / 63 N, above the cap) and are not part of v1 acceptance. |
| B4 | Finger deflection and backlash | Dial indicator on a fingertip while clamping the D105 dummy at 34.7 N. | Tip deflection at most 3 mm (calc 2.6 mm at rated). Rack backlash at most 0.5 mm. |
| B5 | Endurance of the gear train | 1000 open-close cycles at 25 N on the D71 dummy. | Backlash growth at most 0.2 mm, no tooth cracking at the pinion root or the 1.23 mm neck web (the neck web is the known thin section). |

## Phase C. Z module (one day, after the column is assembled)

| ID | Test | Procedure | Pass |
|---|---|---|---|
| C0 | Static checks | Measure the carriage plate flatness, rail parallelism to the column (dial indicator), screw straightness, coupler gap (1.0 mm designed between screw end and motor shaft end). | Rail parallel within 0.2 mm over 0.8 m; no binding by hand over the full stroke. |
| C1 | Speed ramp and step loss | Payload 4.5 kg total (arm mass plus a 2.1 kg dummy). Run the full stroke at 15, 25, 40 mm/s (never above 40) with 5 strokes loaded and empty each, 24 V supply. | Home switch repeats within 0.1 mm, no stall, no resonance band, motor case below 70 C. Set the cruise speed to 0.75 x the last good value. The simulation shows Z speed changes the cycle time by only 5 % (24.3 s at 25 mm/s, 23.0 s at 50 mm/s). |
| C2 | Repeatability | Dial indicator on the carriage at 0.37, 0.70, 1.00 m, approach each position 10 times from above. | Standard deviation at most 0.2 mm. |
| C3 | Power-off hold, both layers | (a) Brake released but motor unpowered, 4.5 kg on the carriage at mid-height, watch 5 minutes (detent plus thread friction layer, T8x4). (b) Brake engaged, same load, 5 minutes. | (a) Drift at most 2 mm; if it creeps the brake is the only holding layer and the arm must never run unattended. (b) No motion. The brake is the guaranteed layer; the T8x4 detent layer is an assumption (25 + 10 mN*m, margin 1.8 at mu 0.05). |
| C4 | Brake transient | Run at 40 mm/s, cut the 24 V rail with the E-stop. Inspect the carriage plate and nut ledge for cracking; repeat 10 times; then load the nut ledge statically to 170 N. | No cracks, no permanent offset. The scaled worst case is 108-172 N on the nut for 1-2 ms (plate 6.4-10.2 MPa across layers against a 5 MPa sustained allowable; not a dynamic FE). In normal stops the controller ramps to zero before the brake sets. |
| C5 | Column lean and stiffness | Hang 2 kg at 0.40 m from J1 with the carriage at the top of the stroke (1.06 m); dial indicators at the carriage and at the column top, forward and sideways, with and without the two tie rods. | Tip deflection at most 2.5 mm without rods, at most 1.5 mm with rods (calc: 4040 alone 2.45 mm worst case, 1.36 mm with rods; joint and foot stiffness are assumptions). Record the rod joint stiffness. |
| C6 | Overturning | Arm extended 0.385 m, 2.1 kg payload, push the carriage top sideways with about 20 N. | No lift-off of the base with the stated ballast (6.5 kg rear half); add ballast otherwise. |
| C7 | Camera clearance | Sweep J1 from -20 to 160 deg and J2 from -130 to +130 deg with no payload at three carriage heights, looking at the camera and bracket. | At least 3 mm clearance everywhere in the operating annulus. CAD (boolean sweep, v0.6.1): the lowest camera point is 7.3 mm above the L1 cover top and no gap below 3 mm was found between the operating arm chain and the Z module (smallest designed gap 4.0 mm, J1 pedestal top to the camera bracket foot). With the earlier v0.6 position the camera overlapped L1 at J1 = -20 deg. |

## Phase D. SCARA arm (one day, on the carriage or bolted to a bench)

| ID | Test | Procedure | Pass |
|---|---|---|---|
| D1 | Range and cable check | Command J1 from -20 to 160 deg, J2 +-130 deg, J3 +-180 deg slowly with no payload. | No collision, no cable strain, no tight spot in the bearings. Cable routing is not designed in CAD (open item): plan the loops at the J1/J2/J3 windows. |
| D2 | Open-loop accuracy | 3 x 3 grid (80 mm pitch) in the reach annulus; photograph the tip with the ArUco board. | RMS error at most 4 mm after fitting link lengths and zero offsets. Backlash of 0.5 deg is 3.4 mm at 0.385 m. The lane funnel tolerates about 10 mm (sim). |
| D3 | Link stiffness and cover bond | Hold 2.4 kg at full reach 0.385 m with the arm folded straight (q2 = 0) and with q2 = 60 deg. Dial indicator at the gripper body. | Vertical droop at most 4 mm straight and at most 6 mm at q2 = 60 deg. Calc: 3.6 mm if the L1 cover acts as a bonded lid, 36-43 mm if not. The independent FE (lead) gives a closed-box twist of 1.16 mrad per N*m against at least 24 mrad per N*m for the open U (21 times softer; the open value is not converged). Bond the cover with a CA or epoxy bead plus all 14 screws; if the droop exceeds the limit, add stiffening before any bottle test. |
| D4 | Current and temperature | 100 pick-place moves with a 600 mL bottle (or a 0.65 kg dummy). Log servo temperature, load and supply current. | Servo temperature below 55 C, no overload faults, peak 12 V supply current below the fuse rating (modelled peak 4.4 A, STS3095 stall 9.8 A each, so keep the torque limits). |
| D5 | Camera and J1 low limit | Command J1 to 0 deg and -20 deg with L2 folded; photograph the clearance to the Orbbec camera. | At least 3 mm (see C7). |

## Phase E. Integrated pick-and-place (two days; v1 gripper on fixture v1.1, open racks at 0.44 m pitch)

These tests show that the arm, Z module, planner and v1 gripper work together on the test fixture. They say nothing about a real cooler: with the desk-research shelf pitch of 0.287-0.381 m the v1 stack cannot enter a shelf tunnel over a 600 mL or larger PET bottle (Figure 9 of the report), which is why Phase H exists.

Order of configurations: (1) level 1 only, 5 lanes (90 mm pitch) with the bay rule, 600 mL; (2) level 0 with the bay rule; (3) mixed SKUs on both levels; (4) optional, only if you want to learn from it: the 3-lane wide set (125 mm pitch) with the deeper back-out, which the simulation does not recommend for 600 mL. Bay rule = drop a bottle into a lane only while slots 0 and 1 (the first 160 mm) of both neighbouring lanes are empty; at most lanes 1, 3, 5 are then full and lanes 2, 4 hold 3 bottles (21 of 25 slots).
Level 0 limits (CAD boolean and MuJoCo agree within 0.4 mm): free lift at the place pose is 21.6 mm in lane 1 and 38.5-39.2 mm in lanes 3 and 5 for the 600 mL; the 11 mm tray rim plus 2 mm needs 13 mm. Tote cell (-300, 0) is unusable for 500 mL and 600 mL (works for cans as the last pick). The 1 L is impossible at level 0 (the L2 cover enters the level-1 plate; it needs a level pitch of at least 461 mm in lanes 2-5 and 486 mm in lane 1).

| ID | Test | Procedure | Pass |
|---|---|---|---|
| E1 | ArUco calibration | Markers 20-23 (80 mm) on the fixture; solve camera-to-base at three Z heights. | Marker centre error at most 3 mm after calibration. |
| E2 | Ten-cycle 600 mL, level 1 | Tote to lane 3 on the 5-lane set, bay rule. | At least 9 of 10 placed in the correct lane; no contact on retreat; cycle time at most 30 s (sim 19.9 s with the bay rule, 24.3 s with the default retreat, Z at 25 mm/s). |
| E3 | Retreat rule check | Same on the 5-lane set: (a) bay rule, (b) default retreat with a bottle in slot 0 of the neighbour lane, (c) fully populated lanes. | (a) at least 9 of 10 clean retreats (sim 45/45). (b) expected to touch the neighbour in most cases (sim 16/45 contact-free). (c) expected to fail: the open gripper lies inside the footprint of the slot-1 bottle (sim 0/45, pad stall forces up to 1.2 kN in the model); do not run (c) with a full lane load. |
| E4 | Level 0 | 600 mL into lanes 1-5, tote cells except (-300, 0); cans into every cell. | At least 9 of 10 (sim 60/60 Monte Carlo, lane 1 20/20); the rim of the tote tray (11 mm above the pocket floor) is cleared with the 25 mm carry lift (lane 1 allows 19.7 mm with the planner's margin). |
| E5 | Mixed 12-bottle run, two levels | 4 cans, 4 x 500/600 mL at level 0 and 1; 1 L only at level 1 (lane clear width 87 mm leaves only 2.5-5.5 mm per side: expect divider contacts, sim 52/60 at 3 mm pick error). | At least 11 of 12 placed, zero drops, zero lane jams. |
| E6 | Wet bottles | Bottles taken out of a fridge so that they sweat. | At least 9 of 10 for 600 mL; record the largest SKU that holds (wet 1 L needs 39 N, above its 34 N limit). |
| E7 | Lane flow | Slide five 600 mL bottles into an empty lane at 6 deg with PTFE tape on the floor. | Every bottle reaches the end stop within 5 s without toppling. Simulation: only mu 0.10 at 6 deg flows without toppling (3.4 s); mu 0.05 topples at every slope, mu 0.2 does not flow. Measure the lane friction first and choose the shim angle (4-10 deg available) from it. |
| E8 | Fault recovery | Topple one bottle in the tote and one in a lane. | Safe stop; an operator clears it in under 2 minutes using the leader arm. |
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

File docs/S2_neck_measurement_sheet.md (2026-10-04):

# S2 neck measurement and slot-gauge sheet (Gate 0), version 3

Version 3, 2026-10-03. Companion to the S2-RC2 master specification and to the Hand README. Version 2 added the cap outer diameter (H). Version 3 replaces the placeholder text about a second test by the real one: four printed slot gauges (about 25 to 40 minutes of printing each) that tell you, before any jaw is printed, whether the real bottles sit in the jaws as drawn. It also carries the exact decision rules from the Hand track, and corrects two numbers that were stale in version 2 (groove height is 5.5 mm, not 4.5 mm; the jaw top is 1 mm below the cap top).

## Why this is the most useful hour before printing the hand

The S2 hand does not squeeze the body of the bottle. Two jaws close around the cap and the neck (the same place where the Japanese restocking robot holds its bottles, as far as the public photos show), and a lip under the plastic ring below the cap catches the bottle if friction on the cap slips. The jaws are cut for a standard 28 mm (PCO 1881) neck. I have only assumed the dimensions below; the measurements and the gauges decide whether the jaws are printed as drawn, with a thinner lip, or not at all.

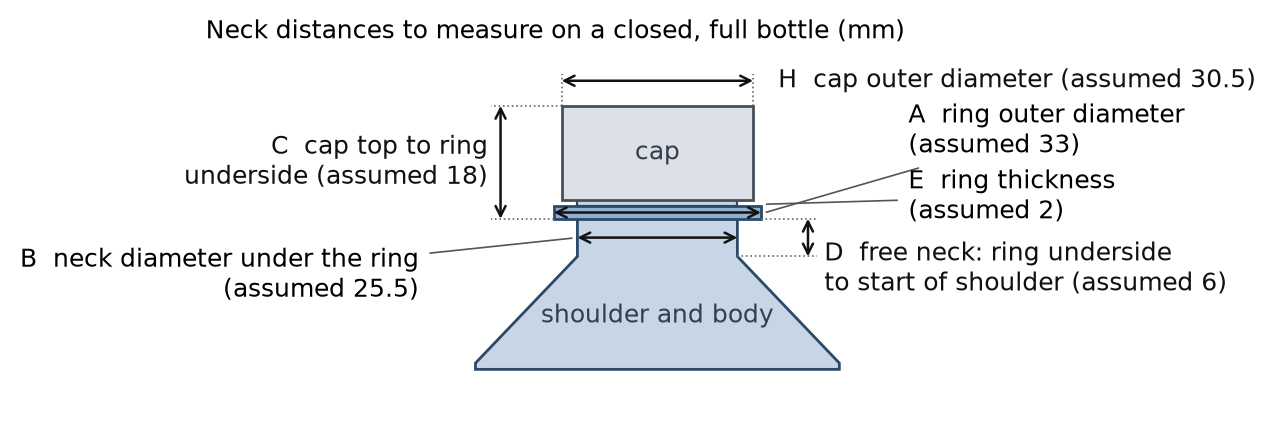
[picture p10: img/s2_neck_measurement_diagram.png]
Neck distances to measure


*Figure 1. Distances A to E and H on the neck. F (widest body diameter) and G (total height, floor to cap top) are measured on the whole bottle. The numbers in the figure are my assumptions for a 28 mm neck; your bottles will differ a little.*

## What you need

- Calipers (0.1 mm reading) and a ruler.
- Closed, full bottles from a store (cold is fine). Best: 3 brands of 600 mL soda or water, plus one 500 mL, one 1 L, one 1.5 L and one 2 L if you can. The same brand from two different batches is worth including.
- Your phone: one photo of each neck from the side, with the ruler next to it.
- The printer: PETG, 0.2 mm layers, 3 perimeters, 15 % infill, no supports, the files exactly as exported (they are already in print pose).

## Part 1. Measure (5 minutes per bottle, no printing)

1. **A, ring outer diameter.** Calipers across the ring, twice, turned 90 degrees between readings. Write "notches" in the ring column if the ring has gaps, notches or flats.
2. **B, neck diameter under the ring.** Calipers on the cylinder just below the ring, twice, 90 degrees apart. If the neck is slightly conical, measure 1 mm under the ring.
3. **C, cap top to ring underside.** Lay the ruler flat on top of the cap and measure down to the underside of the ring (or use the caliper depth rod).
4. **D, free neck.** Height from the underside of the ring to the point where the neck starts to widen into the shoulder. If it widens gradually, use the point where the diameter is 1 mm bigger than B. **This is the number I care about most**: it decides the lip.
5. **E, ring thickness** at its rim.
6. **H, cap outer diameter,** twice, 90 degrees apart, at the widest point of the cap (ribs included). Note if the cap is smooth, ribbed or has a sport nozzle.
7. **F** widest body diameter and **G** total height.
8. Fill one row of `S2_neck_measurement_template.csv` per bottle.

## Part 2. Print the four slot gauges and try every bottle (printing about 2 h in total, testing 15 minutes)

Each gauge is the slot profile of the two jaws (lip, groove and cap-wall steps, back wall, 45 degree lead-ins) cut from a 20 mm slab and joined by a bridge, at the spacing of one cap diameter. The notches in the top edge of the bridge identify it. The gauge is printed lying on its back; in use the notched edge is the top. The Hand track's one-paragraph use note for the gauges (what a good fit and each failure look like) is [s2hand_gauge_use_note.md](s2hand_gauge_use_note.md.html).

| gauge | file | cap position | lip / cap-wall / groove face gap (mm) | notches |
|---|---|---|---|---|
| 1 (print first) | s2hand_gauge_cap30p5.stl | cap 30.5 (nominal) | 28.0 / 30.5 / 35.5 | 2 |
| 2 | s2hand_gauge_cap29p5.stl | cap 29.5 (smallest caps) | 27.0 / 29.5 / 34.5 | 1 |
| 3 | s2hand_gauge_cap32p0.stl | cap 32.0 (largest caps) | 29.5 / 32.0 / 37.0 | 3 |
| 4 (only if D is 3 to 4 mm) | s2hand_gauge_cap30p5_lip2.stl | cap 30.5, 2.0 mm lip | 28.0 / 30.5 / 35.5 | 4 |

**How to use a gauge.** Hold it level with the slot opening toward the bottle. Push it onto the neck from the front, about 1 to 2 mm below the final height, until the cap approaches the back wall; then lift until the ring underside rests on the lip.

**Good:** the cap sits between the cap-wall faces, touching or with a hair of play, in the gauge whose diameter matches it (with about 0.25 mm per side of visible gap for a cap 0.5 mm smaller); the ring lies in the groove with air above and beside it; the lip tip is under the ring and the ring rests on it; the bottle hangs from the lip; the cap top stands about 1 mm above the jaw top (a shorter cap that ends below the jaw top is also fine).

**What a failure means:**

| what you see | meaning | what happens next |
|---|---|---|
| the cap does not enter the faces | the cap is wider than this gauge | try the next larger gauge; if it does not enter the 32.0 gauge, the cap is outside the design range: send me the numbers |
| the ring does not enter the groove, or stops on the lead-in | ring outer diameter above the groove gap minus 0.5 mm, or ring thicker than 5.5 mm | send me A and E; the groove can be widened |
| the gauge cannot be lifted to the ring because the lip does not pass under it | the free neck is too short for the 3.0 mm lip | try gauge 4 (2.0 mm lip); if that also fails, stop (see the table below) |
| the neck wedges against the lip faces | neck diameter above the lip face gap (27.0 / 28.0 / 29.5 mm) | send me B |

## Part 3. What I do with the numbers

| measured | design value | fine as designed | outside this range |
|---|---|---|---|
| A ring outer diameter | 33 | 32.0 to 34.0, every reading | below 32 the lip seat on the ring is narrower than 1.25 mm per side: I enlarge the lip |
| B neck diameter under the ring | 25.5 | 24.5 to 26.5 | above 26.5 the lip faces touch the neck: I widen the lip bore |
| C cap top to ring underside | 18 | 16 to 21 | sets the height of the cap wall; a spread above 1 mm between brands means one jaw setting per product |
| **D free neck** | 6 | **4.0 or more (3.25 or more for a typical 600 mL soda bottle with a 71 mm body)**: baseline jaws with the 3.0 mm lip | **3.0 to 4.0 (2.25 to 3.25 for the typical 600 mL): print the lip2 jaws (2.0 mm lip). Below 3.0 (2.25): stop, the bottle can only be held by friction on the cap (about 600 mL) and I redesign the lip. Send me the file before printing any jaw.** |
| E ring thickness | 2 | 1.5 to 3.0 | the groove is 5.5 mm tall and takes up to 3 mm rings; thicker rings reduce the release window |
| H cap outer diameter | 30.5 | 29.5 to 32.0 | below 29.5 the jaws close on their stop and the clamp force falls (9 to 19 N for caps under 30.3 mm), above 32.0 the cap does not enter |
| F widest body diameter | 65 to 70 | 71 or less | above 71 the bottle does not fit the 73 mm lanes (1 L and larger go to the tote and wide-lane use only) |
| G total height | 237 (600 mL) | any | the shelf pitch needed is G + 5 mm lift + 30 mm shelf structure + 5 mm margin + the hand above the cap (0 mm for the neck hand) |

The rule behind the D row is the boolean result of the Hand track on 216 bottle-neck corner cases: after the hand has been lowered by D millimetres to lift the ring off the lip, the free neck must be at least lip thickness + D - 1.0 mm. The release sequence uses D = 2 mm (lower 2 mm, then open): 4.0 mm for the 3.0 mm lip, 3.0 mm for the 2.0 mm lip, worst corner.

## Part 4 (optional, 0.8 h of printing each). Clip sticks

s2hand_stick_A_C.stl and s2hand_stick_B_C.stl are hand-held heads of the real jaws (lip, groove, cap faces, lead-ins and the lip ramp, with a handle). Hold one stick on each side of a bottle neck (press them together by hand) and check three things: the ring enters the groove and rests on the lip, the lip ramp lets the neck slide forward and out without catching, and the ring stays on the lip when you rock the bottle gently. Pressing by hand is not a force measurement; the pull-out force with the servo clamp is measured later, on the assembled hand (test H3 of the test plan).

## What to send me

1. `S2_neck_measurement_template.csv` (one row per bottle; the new columns record the gauge result).
2. The phone photos (side view of each neck with the ruler).
3. Anything surprising: a cap with a tamper band that stays on, a ring with flats, a bottle that does not seat in any gauge.

## Not needed from you

Weights, friction tests with other materials, store visits, tilt tests. The design uses desk values for those; the Hand and Sim tracks list which of them are assumed.

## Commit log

2026-10-02 Add design versions page, report and documents; move the viewer to viewer/
    [ElRobot2_S1_BOM.csv, ElRobot2_S1_BOM_fasteners.csv, ElRobot2_S1_design_review_log.csv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]
2026-10-04 Add S2-RC2 design report, 3D viewer, documents and landing page update (4 October 2026)
    [ElRobot2_S1_risk_register.csv, ElRobot2_S2_BOM_additions.csv, ElRobot2_S2_print_manifest.csv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]
2026-10-04 Correct swing and can-collision figures in the S2-RC2 report, refresh risk register, design parameters and Wrist README to the latest versions (4 October 2026)
    [ElRobot2_S1_risk_register.csv]
